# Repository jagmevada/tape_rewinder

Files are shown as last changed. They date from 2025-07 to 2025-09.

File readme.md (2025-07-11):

# Cassette Rewinder (Arduino Nano)

A DIY motorized cassette tape rewinder for standard C0 audio cassettes, powered by an Arduino Nano (ATmega328P). This project allows batch rewinding of up to four tapes simultaneously, with automatic stall detection based on current sensing, plus manual controls for starting and stopping all or individual channels.

## Features

* **4-channel PWM motor control** using Timer1 and Timer2
* **Automatic stall detection** via current-sense filtering to stop motors at tape end
* **Manual controls** for global and per-channel start/stop using buttons
* **LED indicators** for motor status (running/stopped)
* **PinChangeInterrupt** library for flexible button wiring on analog and digital pins

## Hardware Requirements

* Arduino Nano (ATmega328P, 16MHz)
* 4× DC motors (e.g., RF-300CA series)
* Current-sense resistors / wiring to measure motor current
* 10× push buttons for start/stop controls
* 5× LEDs (4 channel indicators + 1 master indicator)
* Assorted resistors, wiring, and power supply (6–12V DC)

## Pin Mapping

| Function | Pin | Notes |
| :--- | :--- | :--- |
| **Motor PWM & LED Ch1** | D3 (OC2B)  | PWM output drives motor; LED shows on |
| **Motor PWM & LED Ch2** | D9 (OC1A)  | |
| **Motor PWM & LED Ch3** | D10 (OC1B) | |
| **Motor PWM & LED Ch4** | D11 (OC2A) | |
| **Master ON/OFF LED** | D13 | Indicates global running state |
| **START ALL button** | D2 | External interrupt (FALLING) |
| **STOP ALL button** | D4 | Pin change interrupt (RISING) |
| **START Ch1 button** | D5 | Pin change interrupt (RISING) |
| **START Ch2 button** | D6 | Pin change interrupt (RISING) |
| **START Ch3 button** | D7 | Pin change interrupt (RISING) |
| **START Ch4 button** | D8 | Pin change interrupt (RISING) |
| **STOP Ch1 button** | D12 | Pin change interrupt (RISING) |
| **STOP Ch2 button** | A0 | Pin change interrupt (RISING) |
| **STOP Ch3 button** | A1 | Pin change interrupt (RISING) |
| **STOP Ch4 button** | A2 | Pin change interrupt (RISING) |
| **Current-sense Ch1** | A4 | Analog input for resistor voltage |
| **Current-sense Ch2** | A5 | |
| **Current-sense Ch3** | A6 | Analog-only input |
| **Current-sense Ch4** | A7 | Analog-only input |

> **Note:** A6 and A7 are analog-input only pins; all other A0–A5 can serve as digital or analog.

## Software Setup (PlatformIO)

1. **Install VS Code** and the **PlatformIO IDE** extension.
2. **Create new project** in PlatformIO: select **Arduino Nano** (ATmega328P) and **Arduino** framework.
3. Copy `src/main.cpp` from this repository into your project’s `src/` folder.
4. Add the `PinChangeInterrupt` library dependency in `platformio.ini`:

   ```ini
   lib_deps =
     nickgammon/PinChangeInterrupt@^1.2.3
   ```
5. Build and upload via the PlatformIO toolbar (✅ Build, ➤ Upload).
6. Open Serial Monitor (115200 baud) to view debug output.

## Code Overview

* **`setup()`**: Configures PWM timers (Timer1, Timer2), pin modes, and attach interrupts for buttons.
* **`loop()`**: Samples current-sense inputs, updates a moving-sum filter, and cuts PWM on stall detection after a 1 s delay.
* **Interrupt handlers**:

  * **`startAll()` / `stopAll()`**: Global controls.
  * **`startLedX()` / `stopLedX()`**: Per-channel controls via PCINT.

## Operation

1. **Power on** the Nano and motors.
2. Press **START ALL** (D2) to begin rewinding all channels; LEDs D3, D9, D10, D11 light up.
3. Motors spin at configured PWM duty until either:

   * The tape end is detected (current spike) → that channel stops automatically.
   * **STOP ALL** (D4) or **STOP ChX** button is pressed.
4. To restart an individual channel after auto-stop, press its **START ChX** button (D5–D8).

## Customization

* Adjust **`DUTYx`** in code for motor speed.
* Tune **`thx`** thresholds for different motors or tape conditions.
* Expand to more channels by adding Timer0 (OC0A/OC0B) if needed, but care should be taken not to disrupt `millis()`.

## License

This project is released under the MIT License. 

---

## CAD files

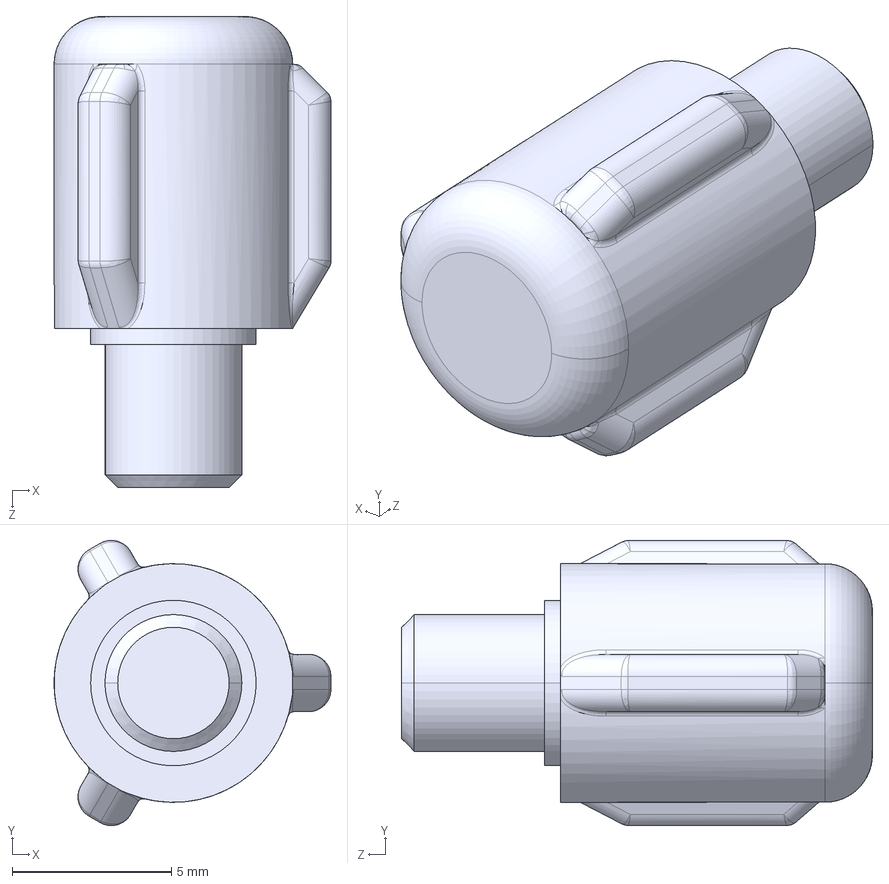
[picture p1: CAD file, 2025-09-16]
CAD/spindle_free.STEP
8.70 x 8.96 x 14.8 mm

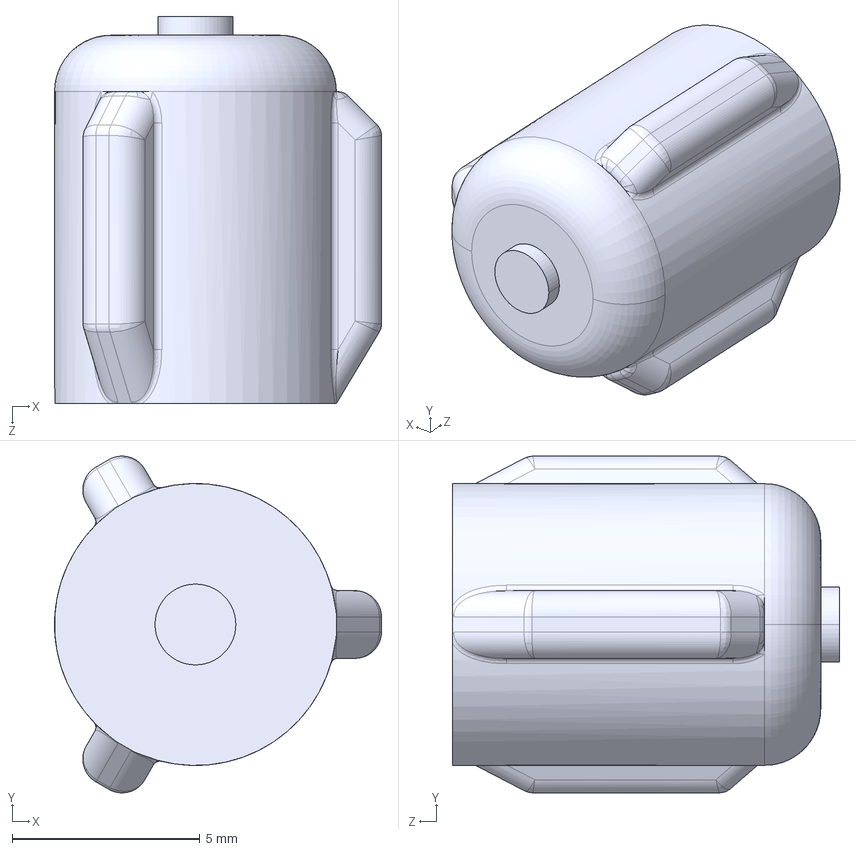
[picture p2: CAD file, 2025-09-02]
CAD/spindle2.15.STEP
8.70 x 8.96 x 10.3 mm

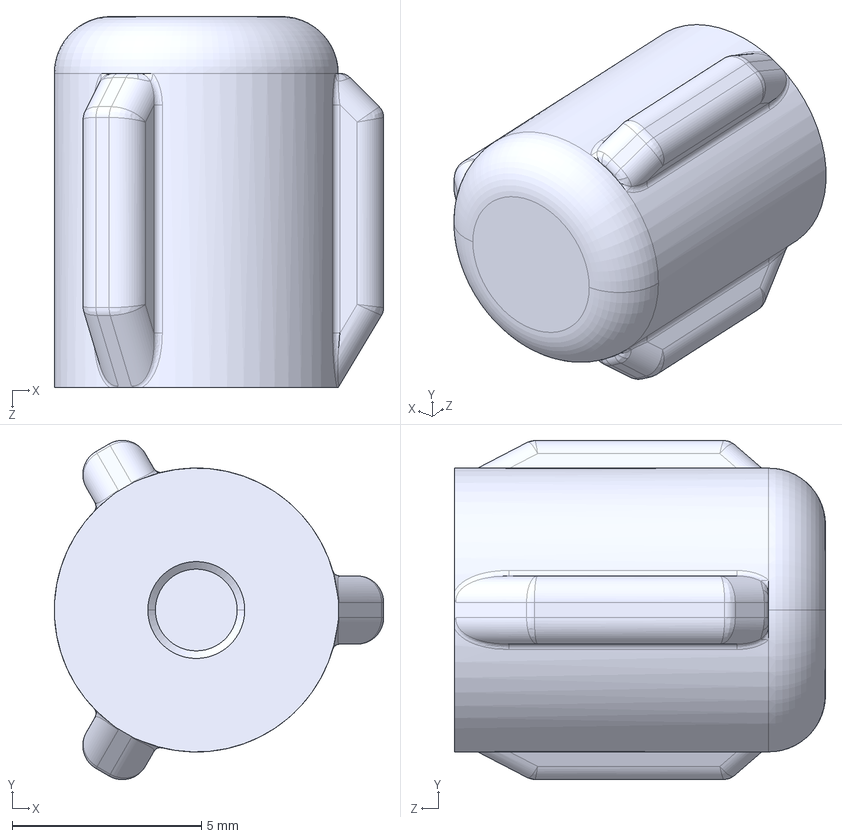
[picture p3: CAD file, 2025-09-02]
CAD/spindle2p16.STEP
8.70 x 8.96 x 9.80 mm

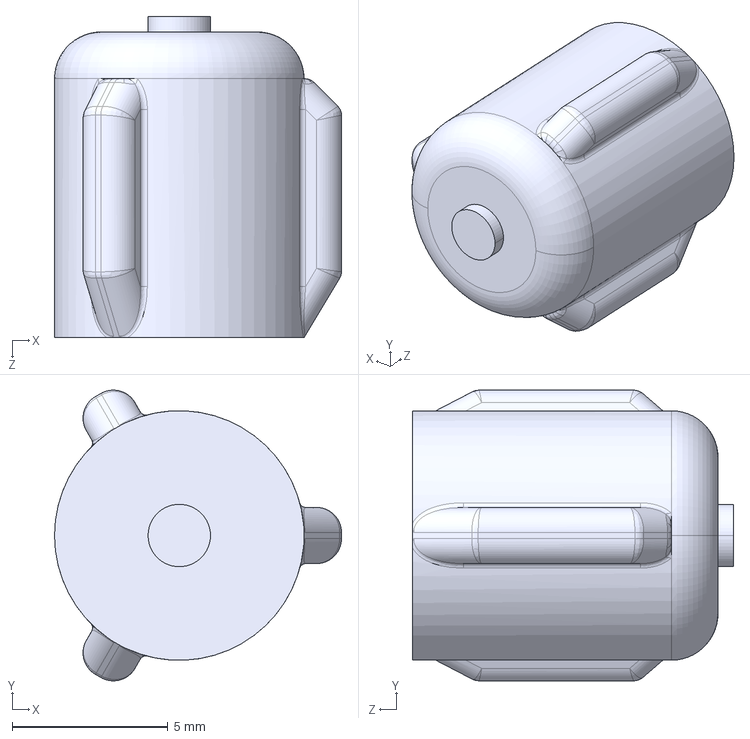
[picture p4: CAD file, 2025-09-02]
CAD/spindle2mm.STEP
9.20 x 9.32 x 10.3 mm

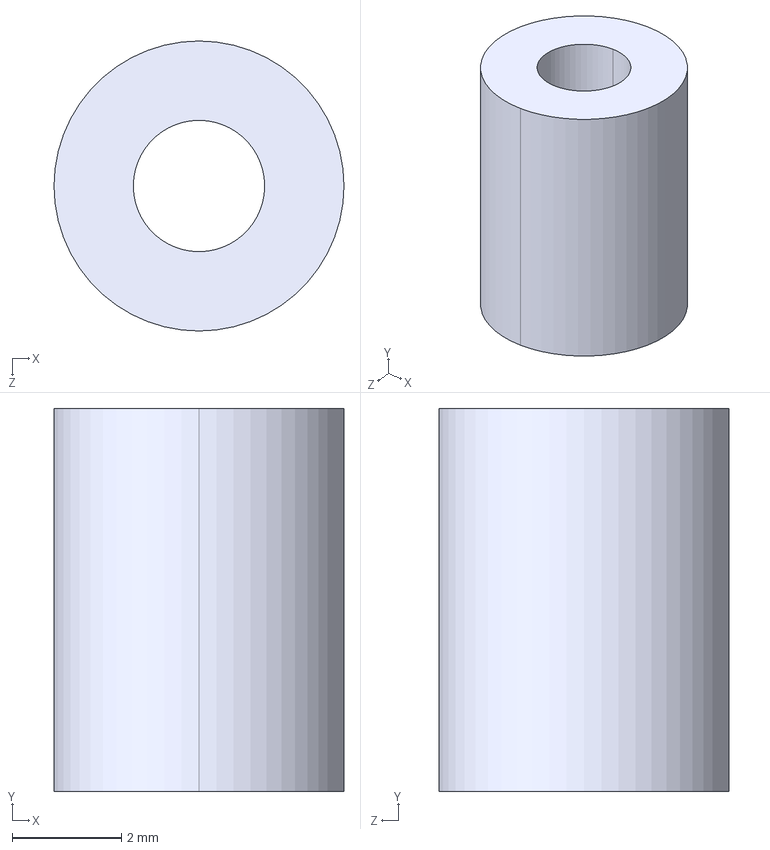
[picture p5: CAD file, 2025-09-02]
CAD/spacer4.STEP
5.30 x 7.00 x 5.30 mm

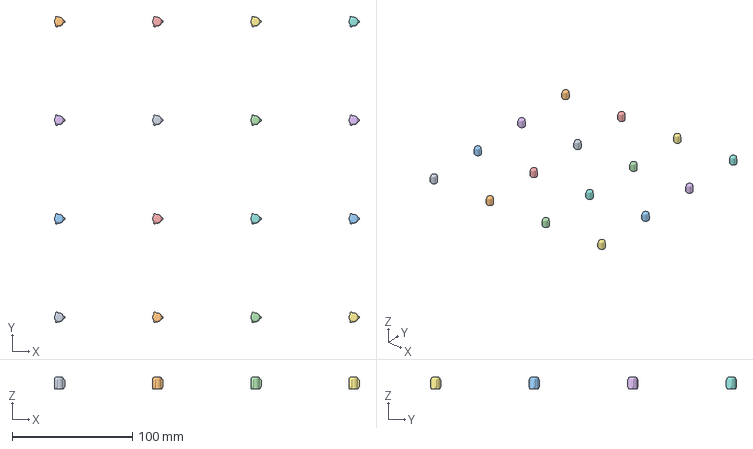
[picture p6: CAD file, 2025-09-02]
CAD/spindle1p5_okx16.3mf
253.9 x 255.1 x 9.80 mm
spindle1p5_ok.STEP x 16

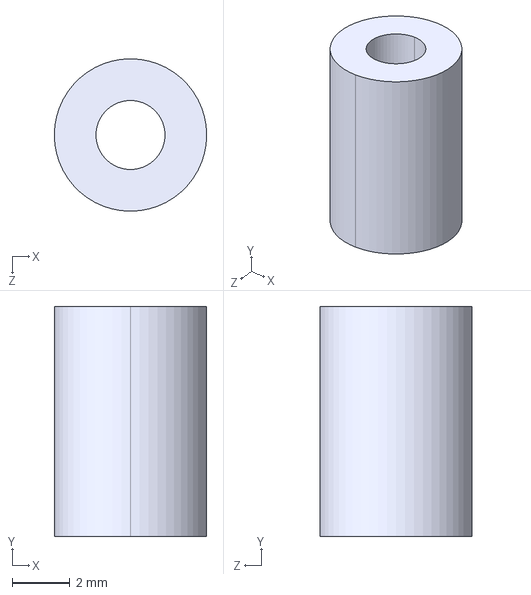
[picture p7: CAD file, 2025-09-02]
CAD/spacer3.STEP
5.30 x 8.00 x 5.30 mm

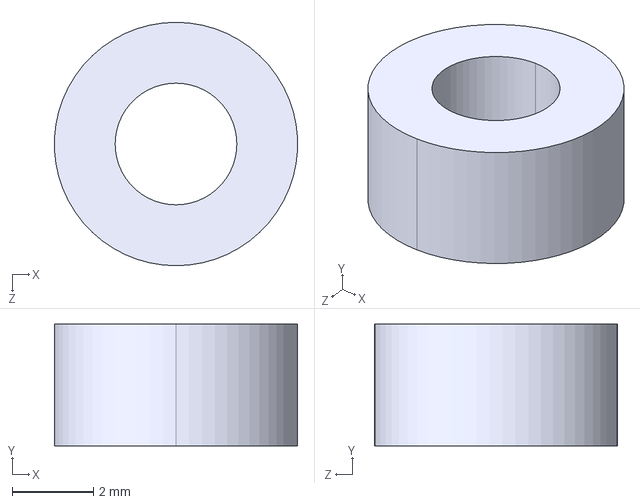
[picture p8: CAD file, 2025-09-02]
CAD/PCB Spacer1.STEP
5.99 x 3.00 x 6.00 mm

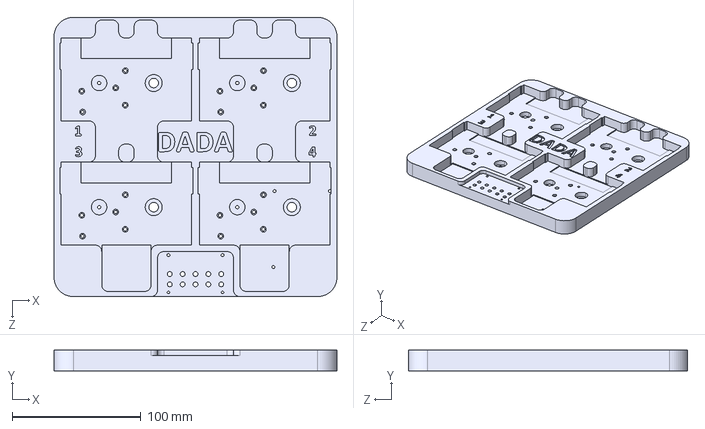
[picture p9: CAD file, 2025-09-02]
CAD/Cassette holder.STEP
220.0 x 16.0 x 217.0 mm

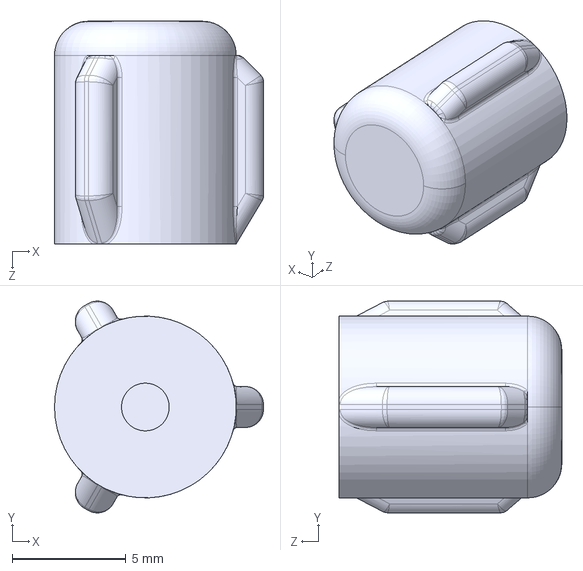
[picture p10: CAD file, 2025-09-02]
CAD/spindle.STEP
9.20 x 9.32 x 9.80 mm

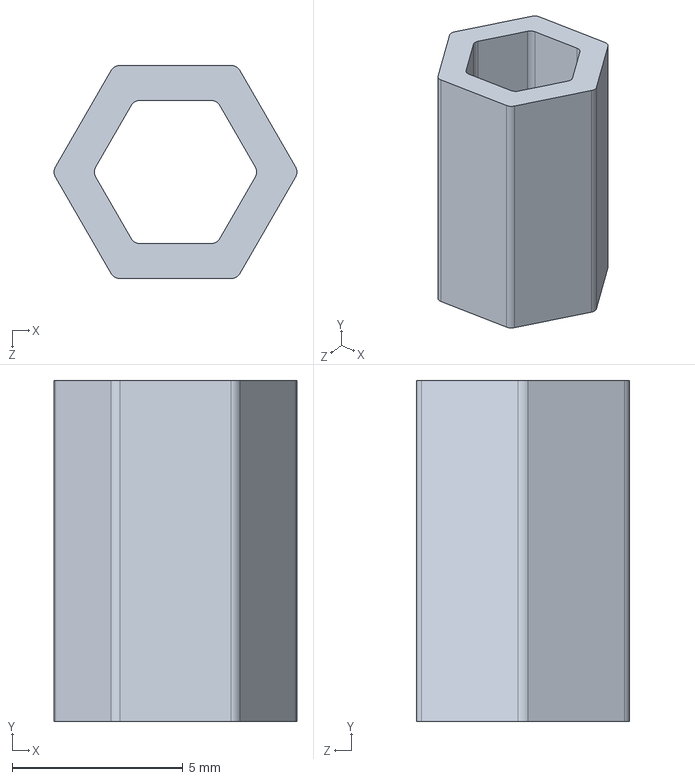
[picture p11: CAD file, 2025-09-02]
CAD/Hex Adapter.STEP
7.12 x 10.0 x 6.25 mm

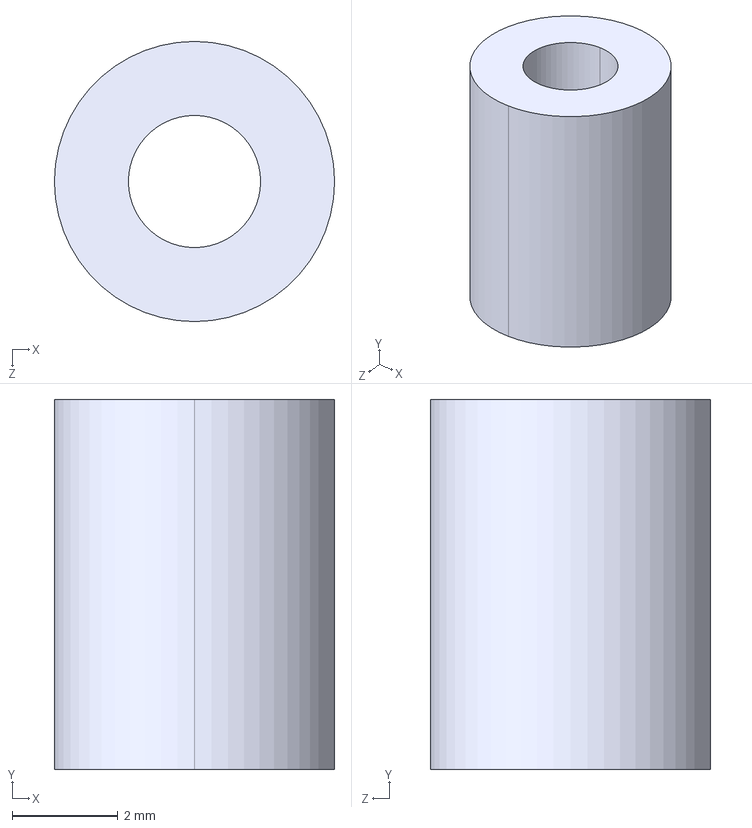
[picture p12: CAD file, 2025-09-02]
CAD/spacer6.STEP
5.30 x 7.00 x 5.30 mm

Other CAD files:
CAD/spindle2.3.STEP
CAD/spindle2.4.STEP
CAD/spindle2.2.STEP
CAD/PCB Spacer6.STEP
CAD/spindle2.1.STEP
CAD/spacer2p6.STEP
CAD/Cassette holder.3mf
CAD/PCB Spacer.STEP
CAD/spacer.SLDPRT
CAD/spacer.STEP
CAD/spacer1.STEP
CAD/spacer45.STEP
CAD/spindle.SLDPRT
CAD/spindle1p5_ok.STEP
CAD/spindle_free.SLDPRT

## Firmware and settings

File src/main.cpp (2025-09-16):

#include <Arduino.h>
#include <PinChangeInterrupt.h>

// #include <algorithm>
#include <moving_average.hpp>

#define DBG
// --- Serial Print Macros for Quick Debugging ---
#ifdef DBG
#define p(x) Serial.print(x)
#define pln(x) Serial.println(x)
#else
#define p(x) ((void)0)
#define pln(x) ((void)0)
#endif

// --- Debounce delay (ms) ---
#define D_DELAY 500

// --- Forward Declarations for Interrupt Handlers ---
void startAll();
void stopAll();
void startLed1();
void startLed2();
void startLed3();
void startLed4();
void stopLed1();
void stopLed2();
void stopLed3();
void stopLed4();

// === Pin Definitions ===
const byte ledPin1 = 3;     // OC2B, Channel 1 PWM & LED indicator####
const byte ledPin2 = 9;     // OC1A, Channel 2 PWM & LED indicator####
const byte ledPin3 = 10;    // OC1B, Channel 3 PWM & LED indicator####
const byte ledPin4 = 11;    // OC2A, Channel 4 PWM & LED indicator####
const byte masterLed = 13;  // Master ON/OFF indicator

const byte startAllButton = 2;  // External Interrupt 0
const byte stopAllButton = 4;   // PCINT for STOP ALL

const byte startButton1 = 5;  // PCINT for START channel 1
const byte startButton2 = 6;  // PCINT for START channel 2
const byte startButton3 = 7;  // PCINT for START channel 3
const byte startButton4 = 8;  // PCINT for START channel 4

const byte stopButton1 = 12;  // PCINT for STOP channel 1
const byte stopButton2 = A0;  // PCINT for STOP channel 2
const byte stopButton3 = A1;  // PCINT for STOP channel 3
const byte stopButton4 = A2;  // PCINT for STOP channel 4

const byte sensePin1 = A4;  // Analog current sense channel 1####
const byte sensePin2 = A5;  // Analog current sense channel 2####
const byte sensePin3 = A6;  // Analog current sense channel 3####
const byte sensePin4 = A7;  // Analog current sense channel 4####

// === Timer & PWM Aliases ===
#define PWM_1 OCR2B  // drives pwmPin1
#define PWM_2 OCR1A  // drives pwmPin2
#define PWM_3 OCR1B  // drives pwmPin3
#define PWM_4 OCR2A  // drives pwmPin4

// === Filter & Control Parameters ===
#define WINDOW_SIZE 4
#define RN (WINDOW_SIZE * 1024.0)
#define DUTY1 190  // 180-190-195
#define DUTY2 190 // 180-190-195
#define DUTY3 190 // 180-190-195
#define DUTY4 190 // 180-190-195
#define th1 0.88 //0.82-0.88-0.9  
#define th2 0.88 //0.82-0.88-0.9
#define th3 0.88 //0.82-0.88-0.9
#define th4 0.88 //0.82-0.88-0.9
#define START_DELAY  1500UL

// === Globals for Moving-Sum Filter ===
// float x1[N], x2[N], x3[N], x4[N];

float y1n, y1n_1 = 0;
float y2n, y2n_1 = 0;
float y3n, y3n_1 = 0;
float y4n, y4n_1 = 0;
float x1 = 0, x2 = 0, x3 = 0, x4 = 0;
unsigned long on1 = 0, on2 = 0, on3 = 0, on4 = 0;

// --- For deferred startAll logic ---
volatile bool startAllFlag = false;

struct PWMState {
  bool to_start = false;
  bool to_stop = false;

  bool ramp_up = false;
  bool ramp_down = false;
  
  uint8_t current_duty = 0;
  uint8_t target_duty = 0;

  unsigned long last_update = 0;
  // unsigned long time_since_start = millis();  //ms to allow higher current during start
};

const unsigned long kRampInterval = 40;  // ms between duty updates
const uint8_t kRampStep = 5;            // duty increment/decrement step

MovingAverage<WINDOW_SIZE> motorFilter[4];

// PWM states for the 4 motors
PWMState pwm_state[4];

void setup() {
  randomSeed(analogRead(A3));
  PWM_1 = 0x00;  // pwm1
  PWM_2 = 0x00;  // pwm2
  PWM_3 = 0x00;  // pwm3
  PWM_4 = 0x00;  // pwm4

  //  --- Timer1: 16-bit Fast PWM, Mode 14 (TOP = ICR1), prescaler 8 ---
  TCCR1A = _BV(WGM11) | _BV(COM1A1) | _BV(COM1B1);
  TCCR1B = _BV(WGM12) | _BV(WGM13) | _BV(CS11);
  ICR1 = 0xFF;  // 8-bit range via 16-bit timer

  // --- Timer2: 8-bit Fast PWM, Mode 3 (TOP = 0xFF), prescaler 8 ---
  TCCR2A = _BV(WGM21) | _BV(WGM20) | _BV(COM2A1) | _BV(COM2B1);
  TCCR2B = _BV(CS21);

  TCCR2A &= ~_BV(COM2B1);  // ledPin1 (D3)
  TCCR1A &= ~_BV(COM1A1);  // ledPin2 (D9)
  TCCR1A &= ~_BV(COM1B1);  // ledPin3 (D10)
  TCCR2A &= ~_BV(COM2A1);  // ledPin4 (D11)

  // PWM / LED pins
  pinMode(ledPin1, OUTPUT);
  pinMode(ledPin2, OUTPUT);
  pinMode(ledPin3, OUTPUT);
  pinMode(ledPin4, OUTPUT);
  pinMode(masterLed, OUTPUT);

  digitalWrite(ledPin1, LOW);
  digitalWrite(ledPin2, LOW);
  digitalWrite(ledPin3, LOW);
  digitalWrite(ledPin4, LOW);
  digitalWrite(masterLed, LOW);

  // Start/Stop buttons
  pinMode(startAllButton, INPUT_PULLUP);
  pinMode(stopAllButton, INPUT_PULLUP);
  pinMode(startButton1, INPUT_PULLUP);
  pinMode(startButton2, INPUT_PULLUP);
  pinMode(startButton3, INPUT_PULLUP);
  pinMode(startButton4, INPUT_PULLUP);
  pinMode(stopButton1, INPUT_PULLUP);
  pinMode(stopButton2, INPUT_PULLUP);
  pinMode(stopButton3, INPUT_PULLUP);
  pinMode(stopButton4, INPUT_PULLUP);

  stopAll();

  // --- Interrupts for Start/Stop ---
  attachInterrupt(digitalPinToInterrupt(startAllButton), startAll, FALLING);
  attachPCINT(digitalPinToPCINT(stopAllButton), stopAll, RISING);

  attachPCINT(digitalPinToPCINT(startButton1), startLed1, RISING);
  attachPCINT(digitalPinToPCINT(startButton2), startLed2, RISING);
  attachPCINT(digitalPinToPCINT(startButton3), startLed3, RISING);
  attachPCINT(digitalPinToPCINT(startButton4), startLed4, RISING);

  attachPCINT(digitalPinToPCINT(stopButton1), stopLed1, RISING);
  attachPCINT(digitalPinToPCINT(stopButton2), stopLed2, RISING);
  attachPCINT(digitalPinToPCINT(stopButton3), stopLed3, RISING);
  attachPCINT(digitalPinToPCINT(stopButton4), stopLed4, RISING);

  Serial.begin(9600);
}

void loop() {
  // Handle deferred startAll logic (non-blocking, not in ISR)
  if (startAllFlag) {
    startLed1();
    startLed2();
    startLed3();
    startLed4();
    startAllFlag = false;
  }
  // Read & normalize currents
  x1 = analogRead(sensePin1) / RN;
  x2 = analogRead(sensePin2) / RN;
  x3 = analogRead(sensePin3) / RN;
  x4 = analogRead(sensePin4) / RN;
  y1n = motorFilter[0].update(x1);
  y2n = motorFilter[1].update(x2);
  y3n = motorFilter[2].update(x3);
  y4n = motorFilter[3].update(x4);

  if (pwm_state[0].ramp_up and
      (millis() - pwm_state[0].last_update > kRampInterval)) {
    if (pwm_state[0].current_duty < pwm_state[0].target_duty) {
      pwm_state[0].current_duty =
          min(pwm_state[0].current_duty + kRampStep, pwm_state[0].target_duty);
      PWM_1 = pwm_state[0].current_duty;
      pwm_state[0].last_update = millis();
    } else {
      pwm_state[0].ramp_up = false;
    }
  }
  if (pwm_state[1].ramp_up and
      (millis() - pwm_state[1].last_update > kRampInterval)) {
    if (pwm_state[1].current_duty < pwm_state[1].target_duty) {
      pwm_state[1].current_duty =
          min(pwm_state[1].current_duty + kRampStep, pwm_state[1].target_duty);
      PWM_2 = pwm_state[1].current_duty;
      pwm_state[1].last_update = millis();
    } else {
      pwm_state[1].ramp_up = false;
    }
  }
  if (pwm_state[2].ramp_up and
      (millis() - pwm_state[2].last_update > kRampInterval)) {
    if (pwm_state[2].current_duty < pwm_state[2].target_duty) {
      pwm_state[2].current_duty =
          min(pwm_state[2].current_duty + kRampStep, pwm_state[2].target_duty);
      PWM_3 = pwm_state[2].current_duty;
      pwm_state[2].last_update = millis();
    } else {
      pwm_state[2].ramp_up = false;
    }
  }
  if (pwm_state[3].ramp_up and
      (millis() - pwm_state[3].last_update > kRampInterval)) {
    if (pwm_state[3].current_duty < pwm_state[3].target_duty) {
      pwm_state[3].current_duty =
          min(pwm_state[3].current_duty + kRampStep, pwm_state[3].target_duty);
      PWM_4 = pwm_state[3].current_duty;
      pwm_state[3].last_update = millis();
    } else {
      pwm_state[3].ramp_up = false;
    }
  }

  if (pwm_state[0].ramp_down and
      (millis() - pwm_state[0].last_update > kRampInterval)) {
    if (pwm_state[0].current_duty > pwm_state[0].target_duty) {
      pwm_state[0].current_duty =
          max(pwm_state[0].current_duty - kRampStep, pwm_state[0].target_duty);
      PWM_1 = pwm_state[0].current_duty;
      pwm_state[0].last_update = millis();
    } else {
      pwm_state[0].ramp_down = false;
      TCCR2A &= ~_BV(COM2B1);  // ledPin1 (D3)
      digitalWrite(ledPin1, LOW);
    }
  }
  if (pwm_state[1].ramp_down and
      (millis() - pwm_state[1].last_update > kRampInterval)) {
    if (pwm_state[1].current_duty > pwm_state[1].target_duty) {
      pwm_state[1].current_duty =
          max(pwm_state[1].current_duty - kRampStep, pwm_state[1].target_duty);
      PWM_2 = pwm_state[1].current_duty;
      pwm_state[1].last_update = millis();
    } else {
      pwm_state[1].ramp_down = false;
      TCCR1A &= ~_BV(COM1A1);  // ledPin2 (D9)
      digitalWrite(ledPin2, LOW);
    }
  }
  if (pwm_state[2].ramp_down and
      (millis() - pwm_state[2].last_update > kRampInterval)) {
    if (pwm_state[2].current_duty > pwm_state[2].target_duty) {
      pwm_state[2].current_duty =
          max(pwm_state[2].current_duty - kRampStep, pwm_state[2].target_duty);
      PWM_3 = pwm_state[2].current_duty;
      pwm_state[2].last_update = millis();
    } else {
      pwm_state[2].ramp_down = false;
      TCCR1A &= ~_BV(COM1B1);  // ledPin3 (D10)
      digitalWrite(ledPin3, LOW);
    }
  }
  if (pwm_state[3].ramp_down and
      (millis() - pwm_state[3].last_update > kRampInterval)) {
    if (pwm_state[3].current_duty > pwm_state[3].target_duty) {
      pwm_state[3].current_duty =
          max(pwm_state[3].current_duty - kRampStep, pwm_state[3].target_duty);
      PWM_4 = pwm_state[3].current_duty;
      pwm_state[3].last_update = millis();
    } else {
      pwm_state[3].ramp_down = false;
      TCCR2A &= ~_BV(COM2A1);  // ledPin4 (D11)
      digitalWrite(ledPin4, LOW);
    }
  }

  // Debug print: print all sensePin1-4 values separated by tabs
  // p(y1n); p("\t");
  // p(y2n); p("\t");
  // p(y3n); p("\t");
  // pln(y4n);

  // Stall detection: shut off if over threshold after 1 second
  if (y1n >= th1 && millis() - on1 > START_DELAY) {
    on1 = millis();
    pwm_state[0].current_duty = 130;
    stopLed1();
    pln("stop1");
  }
  if (y2n >= th2 && millis() - on2 > START_DELAY) {
    on2 = millis();
    pwm_state[1].current_duty = 130;
    stopLed2();
    pln("stop2");
  }
  if (y3n >= th3 && millis() - on3 > START_DELAY) {
    on3 = millis();
    pwm_state[2].current_duty = 130;
    stopLed3();
    pln("stop3");
  }
  if (y4n >= th4 && millis() - on4 > START_DELAY) {
    on4 = millis();
    pwm_state[3].current_duty = 130;
    stopLed4();
    pln("stop4");
  }

  // Print them in one line
  p("y1n: ");
  p(y1n);
  p("\t y2n: ");
  p(y2n);
  p("\t y3n: ");
  p(y3n);
  p("\t y4n: ");
  pln(y4n);

  delay(1);
}

// --- Global START/STOP Handlers ---
void startAll() {
  static unsigned long last = 0;
  unsigned long now = millis();
  if (now - last < D_DELAY) return;
  last = now;
  startAllFlag = true;
}

void stopAll() {
  static unsigned long last = 0;
  unsigned long now = millis();
  if (now - last < D_DELAY) return;
  last = now;
  // PWM_1 = PWM_2 = PWM_3 = PWM_4 = 0;
  // // Force PWM pins low by toggling COMxy1 bits
  // TCCR2A &= ~_BV(COM2B1);  // ledPin1 (D3)
  // TCCR1A &= ~_BV(COM1A1);  // ledPin2 (D9)
  // TCCR1A &= ~_BV(COM1B1);  // ledPin3 (D10)
  // TCCR2A &= ~_BV(COM2A1);  // ledPin4 (D11)
  // digitalWrite(ledPin1, LOW);
  // digitalWrite(ledPin2, LOW);
  // digitalWrite(ledPin3, LOW);
  // digitalWrite(ledPin4, LOW);

  digitalWrite(masterLed, LOW);
  // pln("stopall");

  pwm_state[0].ramp_down = true;
  pwm_state[0].target_duty = 0;

  pwm_state[1].ramp_down = true;
  pwm_state[1].target_duty = 0;

  pwm_state[2].ramp_down = true;
  pwm_state[2].target_duty = 0;

  pwm_state[3].ramp_down = true;
  pwm_state[3].target_duty = 0;
}

// --- Per-Channel START Handlers ---
void startLed1() {
  static unsigned long last = 0;
  unsigned long now = millis();
  if (now - last < D_DELAY) return;
  last = now;
  TCCR2A |= _BV(COM2B1);  // Reconnect timer to pin
  on1 = millis();
  // PWM_1 = DUTY1;

  pwm_state[0].ramp_up = true;
  pwm_state[0].current_duty = 50;
  pwm_state[0].ramp_down = false;
  pwm_state[0].target_duty = DUTY1;
  pln("start1");
}
void startLed2() {
  static unsigned long last = 0;
  unsigned long now = millis();
  if (now - last < D_DELAY) return;
  last = now;
  TCCR1A |= _BV(COM1A1);  // Reconnect timer to pin
  on2 = millis();

  pwm_state[1].ramp_up = true;
  pwm_state[1].current_duty = 50;
  pwm_state[1].ramp_down = false;
  pwm_state[1].target_duty = DUTY2;
  pln("start2");
}
void startLed3() {
  static unsigned long last = 0;
  unsigned long now = millis();
  if (now - last < D_DELAY) return;
  last = now;
  TCCR1A |= _BV(COM1B1);  // Reconnect timer to pin
  on3 = millis();

  pwm_state[2].ramp_up = true;
  pwm_state[2].current_duty = 50;
  pwm_state[2].ramp_down = false;
  pwm_state[2].target_duty = DUTY3;
  pln("start3");
}
void startLed4() {
  static unsigned long last = 0;
  unsigned long now = millis();
  if (now - last < D_DELAY) return;
  last = now;
  TCCR2A |= _BV(COM2A1);  // Reconnect timer to pin
  on4 = millis();

  pwm_state[3].ramp_up = true;
  pwm_state[3].current_duty = 50;
  pwm_state[3].ramp_down = false;
  pwm_state[3].target_duty = DUTY4;
  pln("start4");
}

// --- Per-Channel STOP Handlers ---
void stopLed1() {
  static unsigned long last = 0;
  unsigned long now = millis();
  if (now - last < D_DELAY) return;
  last = now;
  pwm_state[0].ramp_down = true;
  pwm_state[0].ramp_up = false;
  pwm_state[0].target_duty = 0;
  pln("stop1");
}
void stopLed2() {
  static unsigned long last = 0;
  unsigned long now = millis();
  if (now - last < D_DELAY) return;
  last = now;
  pwm_state[1].ramp_down = true;
  pwm_state[1].ramp_up = false;
  pwm_state[1].target_duty = 0;
  pln("stop2");
}
void stopLed3() {
  static unsigned long last = 0;
  unsigned long now = millis();
  if (now - last < D_DELAY) return;
  last = now;
  pwm_state[2].ramp_down = true;
  pwm_state[2].ramp_up = false;
  pwm_state[2].target_duty = 0;
  pln("stop3");
}
void stopLed4() {
  static unsigned long last = 0;
  unsigned long now = millis();
  if (now - last < D_DELAY) return;
  last = now;
  pwm_state[3].ramp_down = true;
  pwm_state[3].ramp_up = false;
  pwm_state[3].target_duty = 0;
  pln("stop4");
}

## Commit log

2025-07-11 simulated all except PWM
2025-07-11 logic analyser added for pwm
2025-09-02 draft functional code
    [Cassette holder.3mf, Cassette holder.STEP, Hex Adapter.STEP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]
2025-09-16 uploaded code on final batch
    [spindle_free.SLDPRT, spindle_free.STEP]
